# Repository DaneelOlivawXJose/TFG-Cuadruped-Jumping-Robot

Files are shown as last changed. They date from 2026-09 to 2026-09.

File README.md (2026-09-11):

<div align="center">

# Jumping Quadruped Robot
### Mechatronic Prototype for Height- and Direction-Controlled Jumping

*A quadruped robot built from scratch with an integrated spring-loaded jump mechanism, capable of executing software-controlled jumps with programmable height and direction.*








</div>

---

## 📽️ Demo

<p align="center">
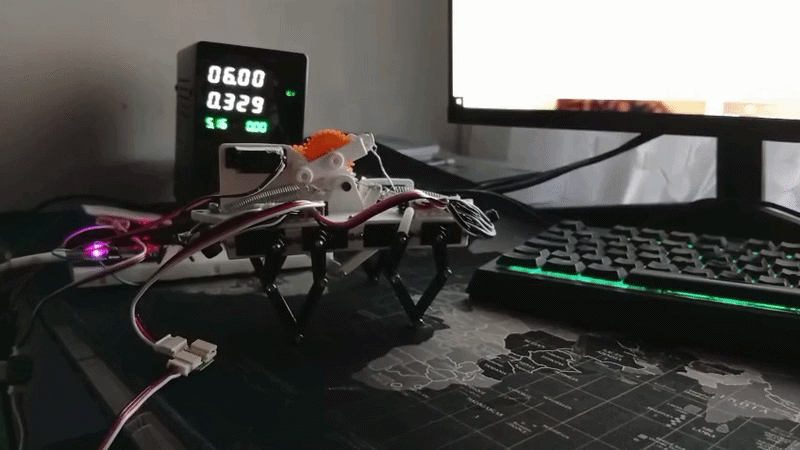
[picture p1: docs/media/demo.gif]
Robot jump demo
  
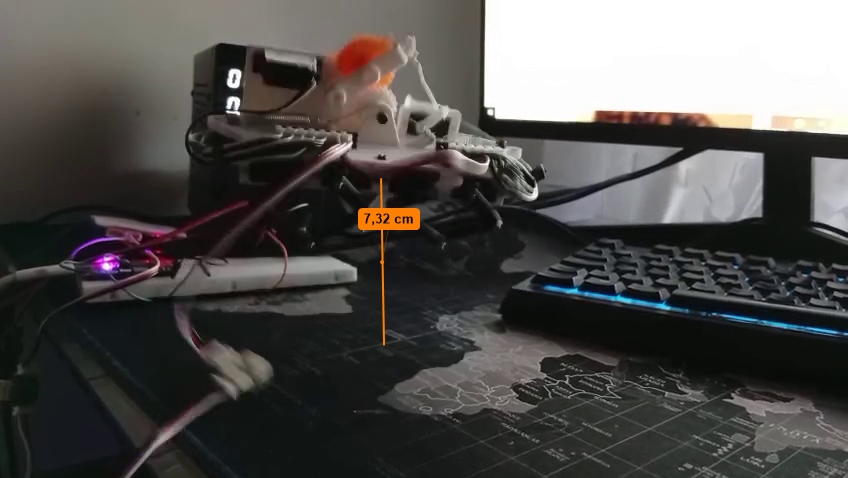
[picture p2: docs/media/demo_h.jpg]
Robot jump height
  
</p>

---

## 🧭 Overview

This repository contains the full mechatronic development of my **Final Degree Thesis (TFG)**: a **quadruped robot designed and built entirely from scratch**, mechanically capable of storing elastic energy in a spring system and releasing it on command to perform a **jump whose height and direction are controlled entirely in software**.

The project was developed end-to-end, across every layer a real robotic product needs:

- **Physical modeling** — the robot's geometry, leg kinematics and jump dynamics were derived analytically, so the software controls a system whose behavior is *understood*, not just tuned by trial and error.
- **Mechanical design** (CAD, linkage synthesis, spring sizing) — SolidWorks.
- **Embedded firmware** (deterministic servo actuation bridge) — ESP32 + micro-ROS + Arduino.
- **Robot software / control** (inverse kinematics, gait generation, jump physics solver, finite-state machine) — ROS 2, C++.

The central idea: give the robot a **single high-level command** — "walk this fast," "turn this much," "jump to this height" — and let the software work out *everything* underneath: joint angles, timing, posture, spring compression, and actuation duration. No per-jump manual calibration.

---

## ✨ Key Features

- 🦵 **Custom 5-bar rhombus leg mechanism** — each leg is a symmetric 5-link linkage, actuated by only 2 servos, giving a lightweight and mechanically robust walking leg with full 2D foot-position control.
- 🧠 **Real-time inverse kinematics** — closed-form, geometry-based IK solver per leg, running at 50 Hz, converting desired foot (x, y) coordinates into servo angles with safety-clamped travel limits.
- 🚶 **Parametric gait engine** — trot-like gait generated from a single global phase clock, with independent per-leg phase offset, adjustable stride length, and live turning compensation (differential stride between left/right or front/rear legs).
- 🚀 **Physics-based jump planner** — for a given target height, the controller sweeps launch angles to find the one that **minimizes the required take-off velocity** (accounting for ground friction and take-off geometry), then derives:
  - the optimal chassis pitch angle,
  - the required spring compression (2 springs in series + 2 in parallel),
  - the exact servo actuation time needed to load that compression through the gearbox/reel transmission.
- 🎯 **Direction control** — jump distance/direction is decoupled from height via the same solver, keeping the mechanism within the physically viable spring-compression range.
- ⚙️ **Spring-loaded release mechanism** — a compact latch (ratchet + trigger servo) loads the spring pack via a geared winch and releases it on a single software command.
- 🔗 **PC ↔ MCU split architecture** — all heavy computation (IK, gait, jump dynamics) runs centralized on a PC via ROS 2; a lightweight ESP32 running micro-ROS acts purely as a real-time servo driver, keeping the embedded side simple and deterministic.
- 🧩 **Finite-state machine control** — clean state machine (`REPOSO`, `ANDAR`, `AGACHADO`, `PREPARAR_SALTO`, `CARGAR_MUELLE`, `LIBERAR_MUELLE`, `RECUPERAR_REPOSO`) governing the full walk → crouch → arm → jump → recover sequence, with built-in safety pauses between behaviors.

---

## 🏗️ How the Architecture Works (Intuitive Overview)

Think of the system as a **brain-and-spine** split:

- **The brain (PC, ROS 2 node `nodo_robot`)** thinks in the world of physics: leg positions in meters, chassis angles in degrees, target jump heights. It never talks about "servo 3" or "PWM 715" — it reasons about *where the foot should be* and *what height the robot should reach*.
- **The spine (ESP32, `nodo_esp32_esclavo`)** doesn't think at all — it just receives a list of 10 numbers 50 times a second and writes them straight to the servos as fast as the serial bus allows. It has zero knowledge of gait, jumping, or geometry.

This split exists on purpose: **all the "smart" logic lives in one place, in a language and environment (ROS 2 / C++ on a PC) that's easy to debug, log, and iterate on**, while the embedded side stays minimal and rock-solid.

```mermaid
flowchart LR
    subgraph PC["🖥️ PC — ROS 2 node: nodo_robot (50 Hz loop)"]
        C[Finite State Machine] --> A[Gait Generator]
        C --> B[Jump Physics Solver]
        A --> D[Inverse Kinematics]
        B --> D
        D --> E["/servo_poses\n(Int32MultiArray, 10 values)"]
        B --> F["/cmd_meta_salto\n(spring-load time, ms)"]
    end

    G["Commands\n/cmd_vel · /cmd_estado · /cmd_salto"] --> C

    subgraph MCU["🔧 ESP32 — nodo_esp32_esclavo (micro-ROS + Arduino)"]
        E --> H[SCServo Driver]
        F --> H
        H --> I["10 Smart Servos\n(8 leg joints + ratchet + trigger)"]
    end

    I -.->|"physical spring loaded"| J["/estado_salto_listo"] --> C
```

**Message flow, step by step:**

1. The PC node computes, every 20 ms, the 10 target servo positions (2 per leg × 4 legs + ratchet + trigger) and publishes them as a single `Int32MultiArray` on `/servo_poses`.
2. The ESP32 subscribes to that same topic. On every message, it loops over its local `ids[]` array and calls `sc.WritePos(id, position, 0, 0)` for each of the 9 physical servos — "0, 0" meaning *move now, at full effort*, with no queued interpolation, since all the interpolation already happened on the PC side.
3. For the jump, a second, independent channel (`/cmd_meta_salto`) tells the ESP32/loading electronics *how long* to run the winch to compress the spring by the exact amount the physics solver calculated — decoupled from the 50 Hz pose stream because it's a one-shot timed action, not a continuous pose.
4. A feedback topic (`/estado_salto_listo`) lets the loading stage tell the PC "the spring is armed," which is what actually triggers the transition into the jump preparation state — the PC never assumes timing, it waits for confirmation.

---

## 🦿 Mechanical Design (SolidWorks)

| Subsystem | Description |
|---|---|
| **Leg linkage** | 5-bar (rhombus) mechanism per leg — two proximal links driven by servos, meeting at a shared distal tip, producing a controllable 2D foot trajectory with only 2 actuators per leg (8 total for 4 legs). |
| **Jump mechanism (2D)** | A single 2-servo, gear-reduced winch mechanism: one servo **loads** the spring pack (via a geared reel/cable transmission), the second servo (**trigger**) instantly **releases** a ratchet, converting stored elastic energy into a controlled jump impulse. |
| **Spring pack** | 4 extension/compression springs arranged as **2 in series + 2 in parallel**, sized to store the energy required for the target jump range while keeping the required compression within the mechanism's physical travel limit. |
| **Chassis** | Designed to tilt (pitch) on command — the take-off angle needed for an efficient jump is achieved by actively inclining the chassis rather than adding an extra actuator. |

<p align="center">
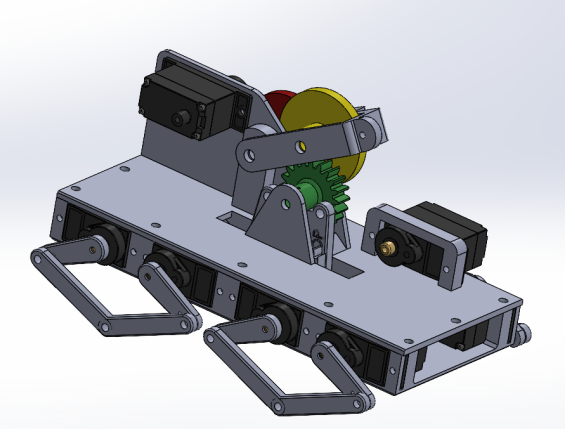
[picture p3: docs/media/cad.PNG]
CAD render
  
</p>

---

## 🧠 Inverse Kinematics — How a Leg "Knows" Where to Put Its Foot

Each leg is modeled as a **triangle-based geometric problem**, not a numerical/iterative solver — this keeps it fast enough to run for all 4 legs, every 20 ms, on a modest CPU.

Given a desired foot position `(x, y)` relative to the leg's hip:

1. The two servo pivots are separated by a fixed distance `D_PATA`, so each pivot "sees" the foot at a different angle and distance — this gives two auxiliary triangles (`α₁, a₁` and `α₂, a₂`).
2. For each triangle, the **law of cosines** is applied between the known link lengths (`L1, L2` proximal / `L3, L4` distal) and the computed distance to the foot, to isolate the internal joint angle.
3. If the required foot position is geometrically unreachable (the law-of-cosines argument falls outside `[-1, 1]`), the solver simply skips the update — a built-in safety check against invalid commands.
4. The two resulting angles (`θ1`, `θ2`) are converted from **degrees to raw servo PWM counts** using a **per-servo linear calibration** (`gradosAPasos`) — every leg has its own measured "horizontal" and "fully-down" PWM reference points, because no two servos or mechanical assemblies are perfectly identical after manual assembly.
5. Every output is **clamped** to a calibrated safe PWM range per servo, so a bad computation can never physically over-drive a joint into the mechanism.

This same IK function is reused everywhere in the code — walking, crouching, tilting for the jump, and holding the recovery posture — the *only* thing that changes between behaviors is what `(x, y, θ_chassis)` gets fed into it.

---

## 🚶 Gait Generation — How the Robot Walks

The walking gait is built from a **single global clock** shared by all 4 legs:

- A continuous timer produces a phase value `t_global ∈ [0, 1)` that repeats every `CICLO_MS` milliseconds — this is the "heartbeat" of the gait.
- Each leg is assigned a **fixed phase offset** (`desfase`): 0.75, 0.50, 0.25, 0.00 — spacing the 4 legs evenly around the gait cycle to produce a stable trot-like pattern where diagonal legs move together.
- Within its own local phase, each leg's foot follows a **two-phase trajectory**:
  - **Flight phase** (`t_local < FRACCION_AIRE`): the foot lifts off the ground and swings forward along a **sinusoidal arc**, from `-stride/2` to `+stride/2` in x, with a smooth lift-and-land height profile in y.
  - **Stance phase** (remaining time): the foot stays on the ground (`y = ALTURA_SUELO`) and slides backward in a straight line from `+stride/2` to `-stride/2`, which is what actually pushes the robot forward.
- **Turning** is achieved without any extra actuator: front legs and rear legs receive **opposite stride-length corrections** (`± compensacion_giro`), so one side of the robot takes shorter steps than the other — exactly like a tank-steering effect, driven purely by `angular.z` from the velocity command.
- **Speed control** is a direct, linear mapping from the commanded `linear.x` / `angular.z` (standard ROS 2 `Twist` message on `/cmd_vel`) to stride length and turn compensation — so the robot can be driven with any standard ROS 2 teleoperation tool.

---

## 🎮 Control — The Finite-State Machine

All robot behavior is governed by a single state machine, updated once per 20 ms control cycle:

```mermaid
stateDiagram-v2
    [*] --> REPOSO
    REPOSO --> ANDAR: /cmd_vel ≠ 0
    ANDAR --> REPOSO: /cmd_vel = 0
    REPOSO --> AGACHADO: /cmd_estado = 1
    REPOSO --> CARGAR_MUELLE: /cmd_salto or /cmd_estado = 2
    CARGAR_MUELLE --> PREPARAR_SALTO: spring loaded\n(/estado_salto_listo = 1)
    PREPARAR_SALTO --> LIBERAR_MUELLE: target posture reached
    LIBERAR_MUELLE --> RECUPERAR_REPOSO: trigger held 0.5 s
    RECUPERAR_REPOSO --> REPOSO: posture recovered (3 s ramp)
```

Two design details worth highlighting:

- **Every state transition passes through a brief `REPOSO` safety pause** (`CICLOS_PAUSA_ESTADO`) before continuing — this prevents abrupt jumps in servo commands whenever the operator switches behaviors, protecting both the mechanism and the servos.
- **Smooth interpolated transitions** (`iniciarTransicion` / `actualizarTransicion`) are used for anything involving posture change over time — crouching down, tilting for the jump, and recovering afterward — using simple **linear interpolation over a fixed duration**, driven by the ROS 2 clock rather than a fixed number of loop iterations, so timing stays consistent regardless of any missed control cycles.

---

## 🧮 The Jump Physics Engine

The core intellectual contribution of the project is `calcularParametrosSalto()`: given only a **target jump height**, the controller solves a small optimization problem in real time, entirely from first-principles physics — no lookup tables, no empirical curve fitting for the trajectory itself.

**Step by step:**

1. **Sweep launch angles** `θ ∈ [atan(1/μ), 90°)`, where the lower bound comes from the **friction cone** — below that angle, the push-off leg would slip on the ground instead of launching the robot.
2. For each candidate angle, compute the **take-off height** contributed by the extended jumping leg's geometry (`z₀ = L·sin θ`), and combine it with the target distance and height to solve the **projectile-motion equation** for the minimum take-off velocity `v₀` that satisfies both constraints simultaneously.
3. **Select the angle that minimizes `v₀²`** — i.e., the most energy-efficient launch geometry for reaching that specific height and distance.
4. Convert the optimal launch angle into the **chassis pitch angle** the robot must adopt before firing, and the **posture height** the legs must be commanded to.
5. **Back-solve the spring compression `Δx`** needed to deliver `v₀`, from the effective combined stiffness of the spring pack (`K1 + K2`, arranged in series/parallel) and an empirically measured **mechanical efficiency factor**, using energy balance under gravity.
6. Convert `Δx` into a **servo actuation time** by unrolling the full mechanical transmission — gear ratios (`Z1…Z5`), winch/reel radius, and maximum servo angular speed — so the loading servo runs for *exactly* as long as needed and no more.
7. **Built-in feasibility check:** if the required spring compression exceeds the mechanism's physical travel limit, the jump is automatically flagged as *not viable* and safely aborted before any hardware command is sent — the operator never has to manually validate a requested height.

This turns "jump to height *h*" into a **single ROS 2 topic publish** (`/cmd_salto`, a `Float64` in meters) — the robot works out the rest, prints a full diagnostic (`v₀`, launch angle, spring compression, posture height) to the log, and either executes or safely refuses the jump.

---

## 🔌 Embedded Firmware (ESP32)

The ESP32 side is intentionally "dumb by design":

- Runs **micro-ROS over serial**, appearing to the PC as a regular ROS 2 node (`nodo_esp32_esclavo`) with a single subscription to `/servo_poses`.
- On every incoming `Int32MultiArray`, it iterates over its local ID map and issues a `WritePos(id, position, time=0, speed=0)` command to each of the 9 **Feetech SCS smart serial servos** over a dedicated UART running at 1 Mbps.
- `time = 0, speed = 0` deliberately disables the servo's own internal interpolation — every trajectory point is already the *final* result of the PC-side interpolation, so the servo is told to snap to it immediately, keeping timing entirely under the 50 Hz ROS 2 loop's control.
- An onboard LED blinks on every received message (useful as a zero-cost "is the link alive" diagnostic) and blinks differently on a micro-ROS initialization failure — a small but genuinely useful debugging aid when the robot is untethered.

---

## 🛠️ Tech Stack

| Layer | Technology |
|---|---|
| Mechanical design | SolidWorks (linkage synthesis, spring sizing, motion study) |
| High-level control | ROS 2 (C++), custom node with 50 Hz control loop |
| Kinematics & dynamics | Closed-form inverse kinematics, projectile-motion jump solver |
| Embedded firmware | ESP32, Arduino framework, micro-ROS |
| Actuation | Feetech SCS smart serial servos (`SCServo` library) |
| Communication | micro-ROS over serial (PC ↔ ESP32), ROS 2 topics for teleop |

---

## 📁 Repository Structure

```
├── cad/                    # SolidWorks parts, assemblies, drawings
├── firmware/
│   └── esp32_servo_bridge/ # Arduino + micro-ROS servo driver
├── ros2_ws/
│   └── src/tfg_salto/      # ROS 2 C++ package: gait, IK, jump planner, FSM
├── docs/
│   └── media/              # Renders, photos, GIFs, diagrams
└── README.md
```

---

## 🚀 Getting Started

### 1. Flash the ESP32
Upload `firmware/esp32_servo_bridge` via Arduino IDE / PlatformIO (requires the `micro_ros_arduino` and `SCServo` libraries).

### 2. Bring up the micro-ROS bridge on the PC
```bash
ros2 run micro_ros_agent micro_ros_agent serial --dev /dev/ttyUSB0
```

### 3. Build and launch the robot controller
```bash
colcon build --packages-select tfg_salto
source install/setup.bash
ros2 run tfg_salto tfg_robot
```

### 4. Drive it
```bash
python3 teleop_teclado.py
```

### 5. Command specific behaviors
| Topic | Type | Effect |
|---|---|---|
| `/cmd_vel` | `geometry_msgs/Twist` | Walk / turn (linear.x → stride length, angular.z → turn compensation) |
| `/cmd_estado` | `std_msgs/Int32` | `0` walk · `1` crouch · `2` load spring · `3` idle |
| `/cmd_salto` | `std_msgs/Float64` | Trigger a full jump sequence to a target height (m) |
| `/estado_salto_listo` | `std_msgs/Int32` | (internal) confirms the spring is physically armed |

**Example — jump to 4 cm:**
```bash
ros2 topic pub -1 /cmd_salto std_msgs/msg/Float64 "{data: 0.04}"
```

The controller will log the full computed jump plan before executing it, e.g. take-off velocity, optimal launch/pitch angle, required spring compression, and target posture height — making every jump fully traceable and reproducible.

---

## 📊 Mechanism Results

| Metric | Value |
|---|---|
| Target jump height range tested | **2-6cm** (e.g. 2–6 cm) |
| Maximum controlled jump height achieved | **6cm** |
| Mechanism efficiency | **75%** |
| Jump height accuracy (measured vs. commanded) | **99,6%** |
| Jump distance / direction range | **TBD** |
| Spring-loading time (typical) | **7s** (derived from `movimiento_servo_`, ms) |
| Full jump sequence duration (load → launch → recover) | **15s** |
| Total robot mass | **370g** |

---

## 🔭 Future Work

- Closed-loop landing detection and impact absorption
- IMU-based feedback for in-flight orientation correction
- Onboard (non-centralized) computation for full autonomy
- 3D jump control (adding lateral steering to the current 2D jump plane)

---

## 👤 Author

**Jose Segura Montes** — Bachelor's Thesis (TFG), Degree in Electronics, Robotics and Mechatronics, Universidad de Málaga, [2026]
📧 jose.segura.montes@gmail.com · 🔗 [LinkedIn](www.linkedin.com/in/jose-segura-montes) · 🔗 [Portfolio](https://portfolio-github-8fqt.vercel.app)

---

## 📄 License

This project is licensed under the MIT License — see [`LICENSE`](LICENSE) for details.

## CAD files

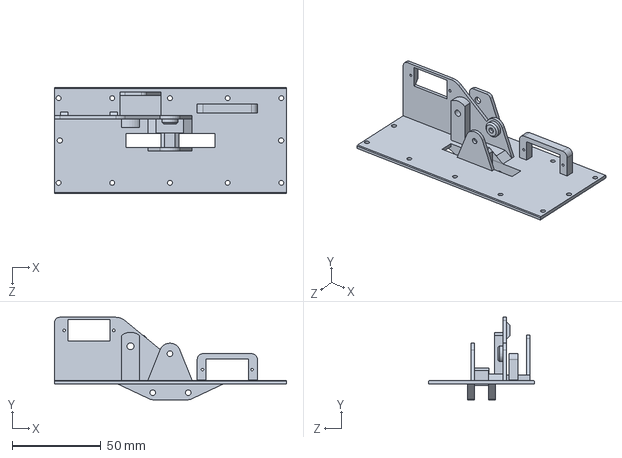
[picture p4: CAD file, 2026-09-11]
cad/2026 Jumper Robot/vehicle/chasis superior completo.SLDPRT
131.0 x 46.6 x 60.0 mm

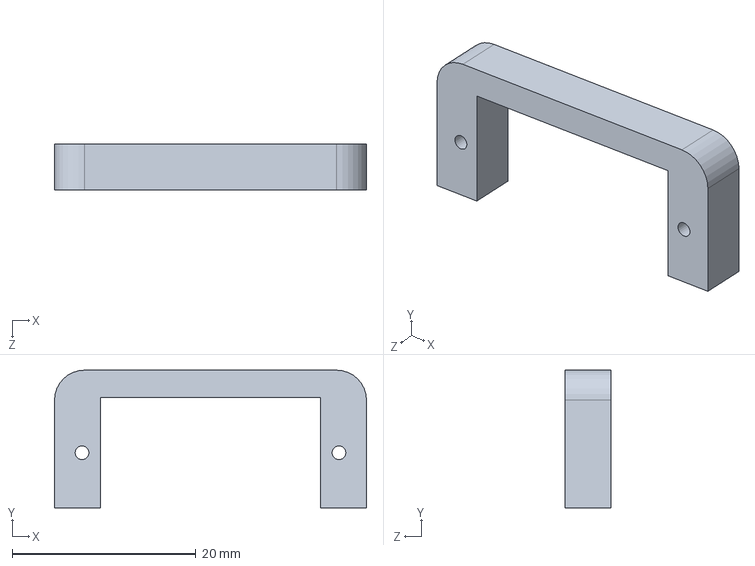
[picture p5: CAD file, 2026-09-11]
cad/2026 Jumper Robot/vehicle/soporteservo.SLDPRT
34.0 x 15.0 x 5.00 mm

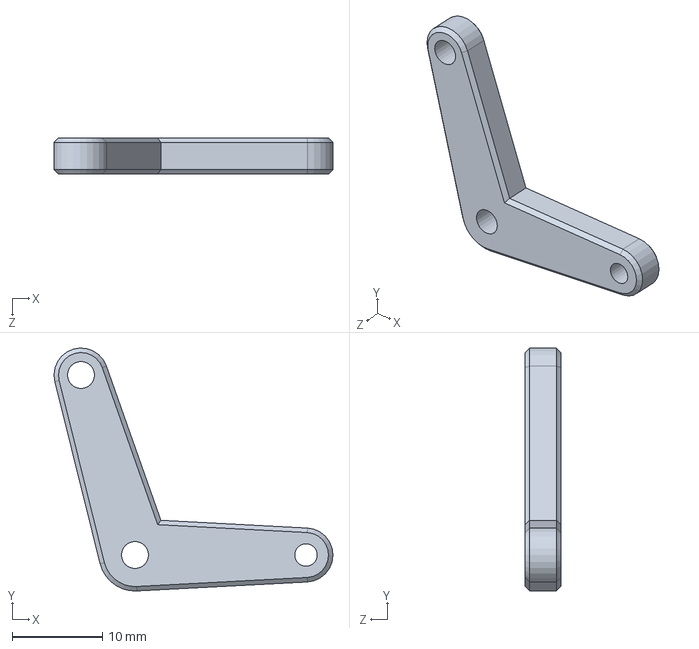
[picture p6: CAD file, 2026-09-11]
cad/2026 Jumper Robot/vehicle/link1-central-2.SLDPRT
31.0 x 27.0 x 4.00 mm

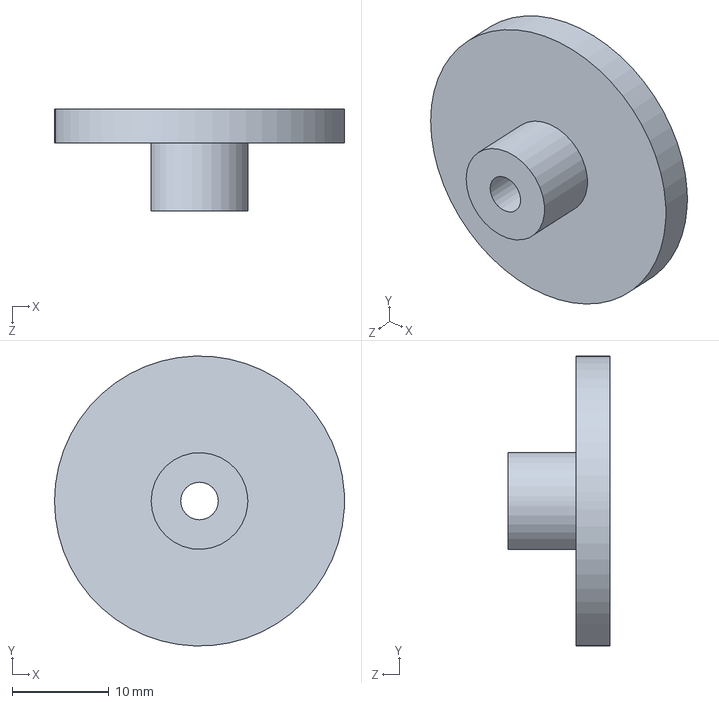
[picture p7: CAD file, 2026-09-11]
cad/2026 Jumper Robot/vehicle/engranaje30x10.SLDPRT
30.0 x 30.0 x 10.5 mm

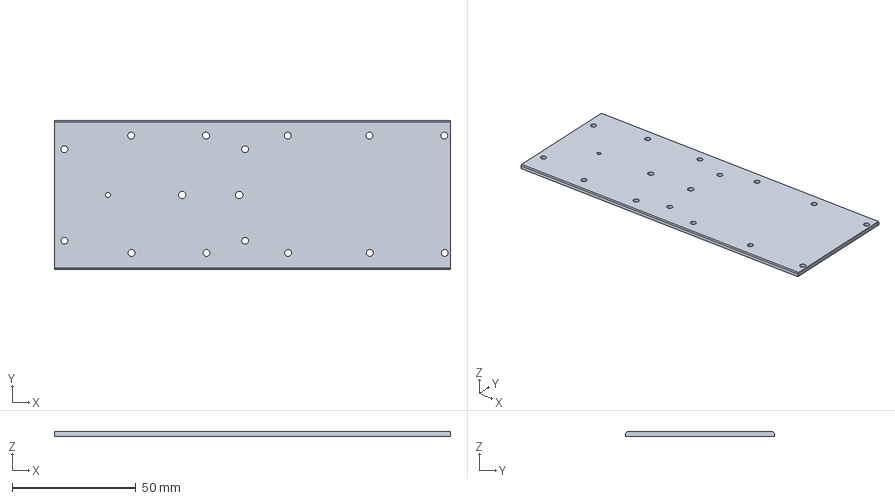
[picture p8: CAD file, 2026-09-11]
cad/2026 Jumper Robot/vehicle/Tapa-chasis.3mf
160.0 x 60.0 x 2.00 mm

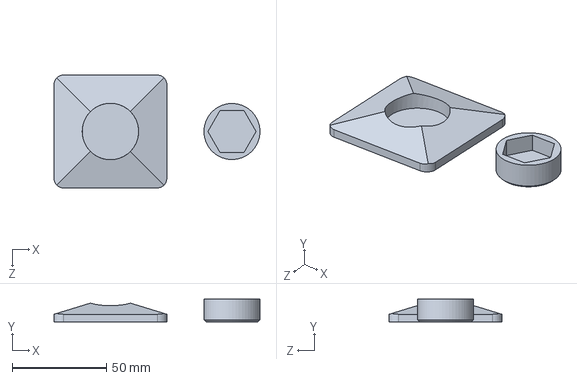
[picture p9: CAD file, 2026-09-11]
cad/2026 Jumper Robot/vehicle/base patas estructura cámaras.SLDPRT
109.5 x 12.0 x 60.0 mm

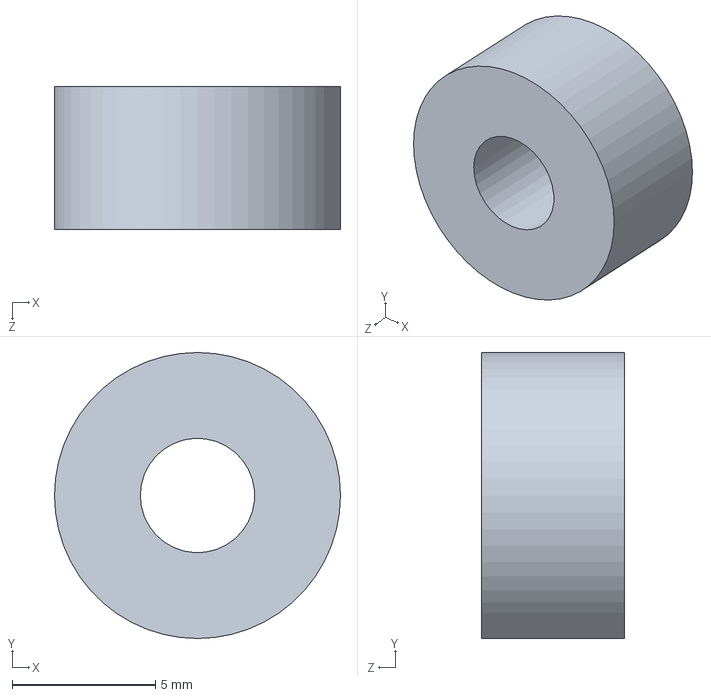
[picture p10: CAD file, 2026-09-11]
cad/2026 Jumper Robot/vehicle/engranaje-10.SLDPRT
10.0 x 10.0 x 5.00 mm

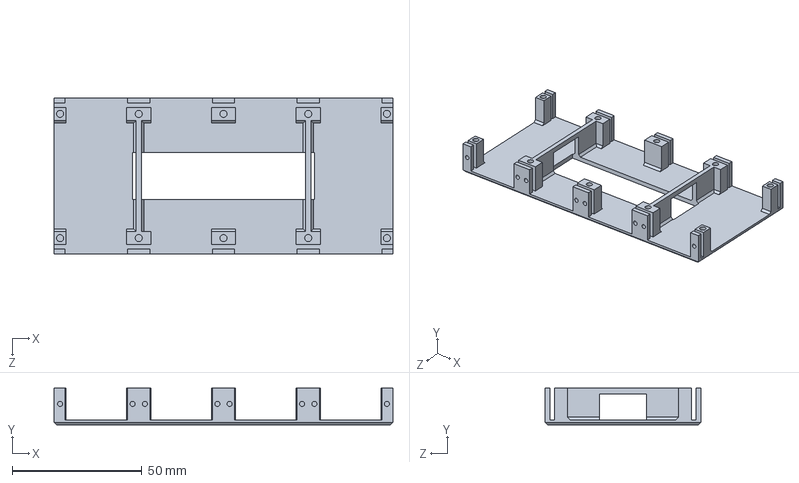
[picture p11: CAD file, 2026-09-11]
cad/2026 Jumper Robot/vehicle/chasis.SLDPRT
130.4 x 14.2 x 60.0 mm

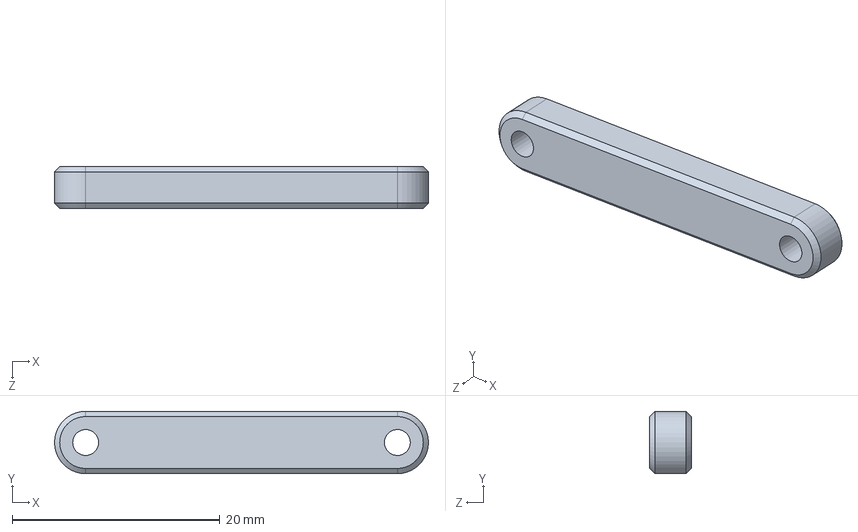
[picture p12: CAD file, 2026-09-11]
cad/2026 Jumper Robot/vehicle/link2-central.SLDPRT
36.0 x 6.00 x 4.00 mm

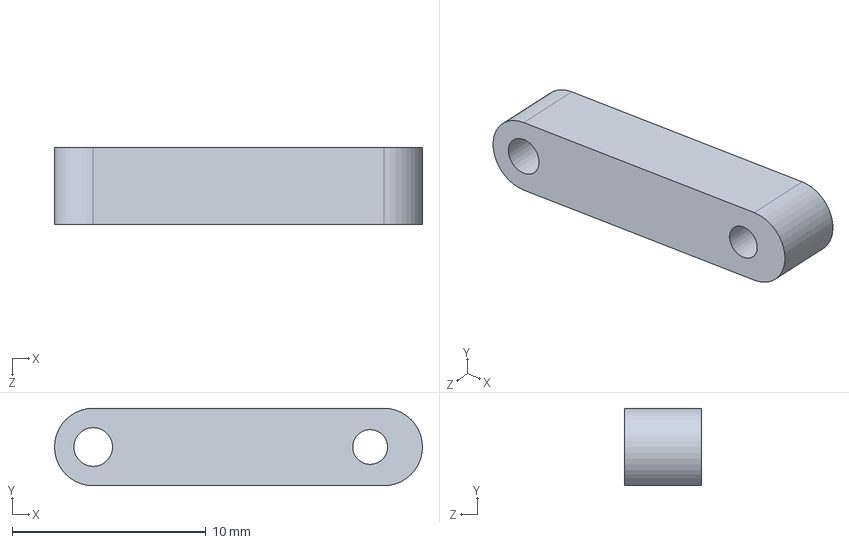
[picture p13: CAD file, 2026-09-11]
cad/2026 Jumper Robot/vehicle/horn_aprox.SLDPRT
19.0 x 4.00 x 4.00 mm

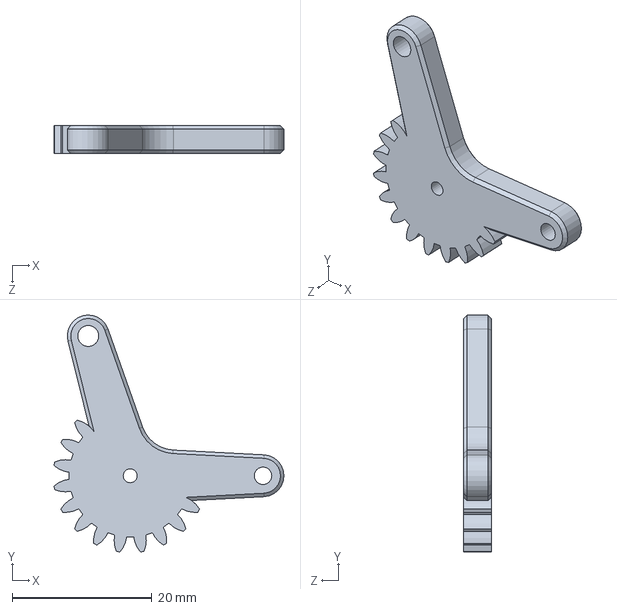
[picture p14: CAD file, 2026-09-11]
cad/2026 Jumper Robot/vehicle/link1-central.SLDPRT
32.9 x 33.9 x 4.00 mm

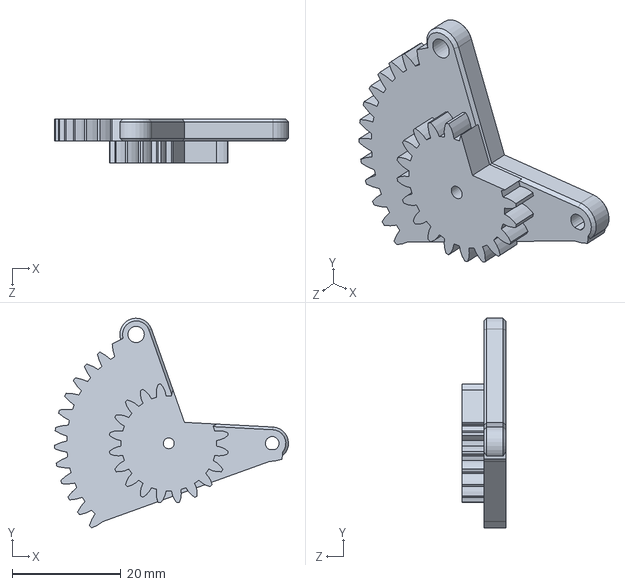
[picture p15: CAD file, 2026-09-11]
cad/2026 Jumper Robot/vehicle/link1-LEFT-central.SLDPRT
43.0 x 38.5 x 8.00 mm

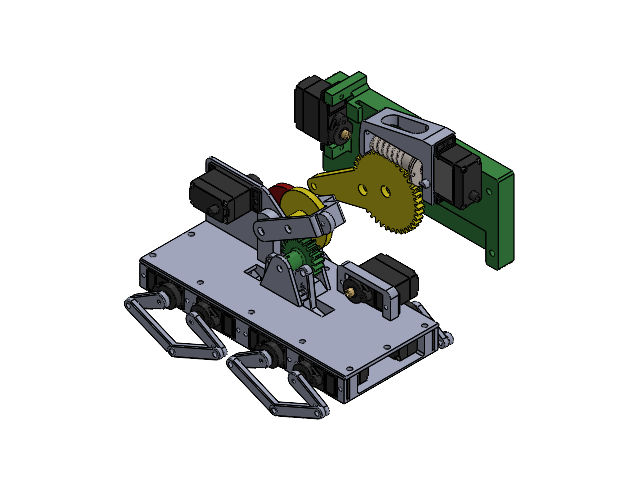
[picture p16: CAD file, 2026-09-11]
cad/2026 Jumper Robot/vehicle/Ensamblaje global.SLDASM
base2
main-gear3
91772A071_NO THREADS_Passivated 18-8 Stainless Steel Pan Head Phillips Screw_1.step x 48
eBom-FreeParts_1.step x 12
bloque_worm2
polea 10_modulo 1 simple
chasis
link1 x 8
link2 x 8
Tapa-chasis
link1-central-2
link2-central x 2
link1-LEFT-central-2
soporte carrete y engranajes
ejepolea
engranaje30x10 x 2
bloqueo resorte
soporteservo

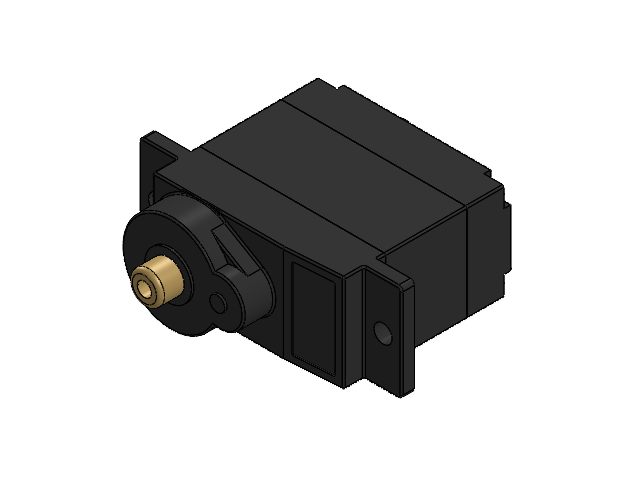
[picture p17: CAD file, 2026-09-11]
cad/2026 Jumper Robot/vehicle/Feetech SCS0009 v9.SLDASM
91772A071_NO THREADS_Passivated 18-8 Stainless Steel Pan Head Phillips Screw_1.step x 4
eBom-FreeParts_1.step

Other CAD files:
cad/2026 Jumper Robot/vehicle/Ensamblaje Vahículo Saltador 2_2024.SLDASM
cad/2026 Jumper Robot/vehicle/Ensamblaje Pata.SLDASM
cad/2026 Jumper Robot/vehicle/Ensamblaje chasis superior.SLDASM
cad/2026 Jumper Robot/vehicle/Ensamblaje chasis superiopr.SLDASM
cad/2026 Jumper Robot/vehicle/Ensamblaje chasis superior.STL
cad/2026 Jumper Robot/vehicle/Tapa-chasis.STL
cad/2026 Jumper Robot/vehicle/base patas estructura cámaras.3mf
cad/2026 Jumper Robot/vehicle/base patas estructura cámaras.STL
cad/2026 Jumper Robot/vehicle/bloqueo resorte.3mf
cad/2026 Jumper Robot/vehicle/bloqueo resorte.SLDPRT
cad/2026 Jumper Robot/vehicle/bloqueo resorte.STL
cad/2026 Jumper Robot/vehicle/chasis superior completo.3mf
cad/2026 Jumper Robot/vehicle/chasis superior completo.STL
cad/2026 Jumper Robot/vehicle/chasis.3mf
cad/2026 Jumper Robot/vehicle/chasis.STL
cad/2026 Jumper Robot/vehicle/ejepolea.3mf
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

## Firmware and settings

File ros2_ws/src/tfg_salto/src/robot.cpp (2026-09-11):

#include "tfg_salto/robot.hpp"


Robot::Robot() : Node("nodo_robot")
{
    // --- Inicializar patas: {canal_s1, canal_s2, pwm_h_s1, pwm_d_s1, pwm_h_s2, pwm_d_s2}, desfase, inversor_x ---
    misPatas_[0] = { {1, 8, 299, 584, 941, 671}, 0.75f,  1.0f };
    misPatas_[1] = { {3, 2, 715, 992, 890, 634}, 0.50f,  1.0f };
    misPatas_[2] = { {7, 6, 183, 466, 907, 630}, 0.25f, -1.0f };
    misPatas_[3] = { {4, 5, 650, 310, 475, 754}, 0.00f,  1.0f };

    tiempo_inicio_ = this->now();

    // --- Publishers ---
    pub_poses_      = this->create_publisher<std_msgs::msg::Int32MultiArray>("servo_poses",    10);
    pub_meta_salto_ = this->create_publisher<std_msgs::msg::Int32>          ("cmd_meta_salto", 10);

    // --- Subscriptores ---
    sub_vel_ = this->create_subscription<geometry_msgs::msg::Twist>(
        "cmd_vel", 10, std::bind(&Robot::cmd_vel_callback, this, std::placeholders::_1));

    sub_estado_ = this->create_subscription<std_msgs::msg::Int32>(
        "cmd_estado", 10, std::bind(&Robot::cmd_estado_callback, this, std::placeholders::_1));

    sub_salto_ = this->create_subscription<std_msgs::msg::Float64>(
        "cmd_salto", 10, std::bind(&Robot::cmd_salto_callback, this, std::placeholders::_1));

    sub_salto_listo_ = this->create_subscription<std_msgs::msg::Int32>(
        "estado_salto_listo", 10, std::bind(&Robot::salto_listo_callback, this, std::placeholders::_1));

    // --- Timer principal: 50 Hz (20 ms) ---
    timer_control_ = this->create_wall_timer(
        20ms, std::bind(&Robot::bucle_control_callback, this));

    RCLCPP_INFO(this->get_logger(), "Nodo Robot iniciado.");
}

Robot::~Robot()
{
    RCLCPP_INFO(this->get_logger(), "Apagando nodo del robot.");
}

// ============================================================
// BUCLE PRINCIPAL (50 Hz)
// ============================================================

void Robot::bucle_control_callback()
{
    // Al cambiar de estado, se hace una pausa de 1 s en REPOSO antes de continuar
    if (cambiado_) {
        estado_previo_ = estado_actual_;
        estado_actual_ = REPOSO;
        ciclos_espera_ = CICLOS_PAUSA_ESTADO;
        cambiado_ = false;
    }

    switch (estado_actual_) {
        case ANDAR:           estado_andar();           break;
        case AGACHADO:        estado_agachado();        break;
        case REPOSO:          estado_reposo();          break;
        case PREPARAR_SALTO:  estado_preparar_salto();  break;
        case CARGAR_MUELLE:   estado_cargar_muelle();   break;
        case LIBERAR_MUELLE:  estado_liberar_muelle();  break;
        case RECUPERAR_REPOSO: estado_recuperar_reposo(); break;
    }
}

// ============================================================
// LÓGICA DE ESTADOS
// ============================================================

void Robot::estado_andar()
{
    // Tiempo global normalizado [0, 1) dentro del ciclo de marcha
    auto tiempo_actual = this->now() - tiempo_inicio_;
    double ms = tiempo_actual.nanoseconds() / 1e6;
    float t_global = static_cast<float>(fmod(ms, CICLO_MS)) / CICLO_MS;

    std_msgs::msg::Int32MultiArray msg;
    msg.data.resize(10);

    for (int i = 0; i < 4; i++) {
        // Cada pata tiene su desfase de fase en el ciclo
        float t_local = fmod(t_global + misPatas_[i].desfase, 1.0f);

        // Las patas delanteras (0,1) restan la compensación y las traseras (2,3) la suman
        float longitud = longitud_paso_ + ((i < 2) ? -compensacion_giro_ : compensacion_giro_);

        float x, y;
        calcularTrayectoriaPaso(t_local, longitud, x, y);

        int s1, s2;
        calcularPataIK(x * misPatas_[i].inversor_x, y, misPatas_[i], s1, s2);
        msg.data[i*2]   = s1;
        msg.data[i*2+1] = s2;
    }

    msg.data[8] = 930;                    // Ratchet en posición de marcha
    msg.data[9] = SERVO_GATILLO_CERRADO;  // Gatillo cerrado durante la marcha
    pub_poses_->publish(msg);
}

void Robot::estado_agachado()
{
    // Baja suavemente el chasis hasta y = 0.02 m (máximo agachado)
    constexpr float Y_AGACHADO = 0.02f;
    constexpr float PASO_BAJA  = 0.0005f;

    if (altura_chasis_ > Y_AGACHADO) {
        altura_chasis_ = std::max(Y_AGACHADO, altura_chasis_ - PASO_BAJA);
    }

    publicarPoses(0.0f, altura_chasis_, 0.0f, 0, SERVO_GATILLO_CERRADO);
}

void Robot::estado_reposo()
{
    constexpr float PASO_ALTURA = 0.0005f;
    constexpr float PASO_THETA  = 0.5f;    // Grados por ciclo al recuperar inclinación

    // Recuperar altura suavemente hacia Y_REPOSO
    if (std::abs(altura_chasis_ - Y_REPOSO) > PASO_ALTURA) {
        altura_chasis_ += (Y_REPOSO > altura_chasis_) ? PASO_ALTURA : -PASO_ALTURA;
    } else {
        altura_chasis_ = Y_REPOSO;
    }

    // Recuperar inclinación suavemente hacia 0°
    theta_actual_ = std::max(0.0f, theta_actual_ - PASO_THETA);

    // Si el estado previo era PREPARAR_SALTO, el muelle sigue cargado: no soltar el gatillo
    int gatillo = (estado_previo_ == PREPARAR_SALTO) ? SERVO_GATILLO_ABIERTO : SERVO_GATILLO_CERRADO;

    publicarPoses(0.0f, altura_chasis_, theta_actual_ * (M_PI / 180.0f), 0, gatillo);

    // Volver al estado anterior tras la pausa
    if (ciclos_espera_ > 0) {
        ciclos_espera_--;
    } else {
        estado_actual_ = estado_previo_;
    }
}

void Robot::estado_cargar_muelle()
{
    // Mantener las patas rígidas en reposo con el gatillo armado
    publicarPoses(0.0f, altura_chasis_, 0.0f, 0, SERVO_GATILLO_ABIERTO);

    // Enviar la orden de tensado al ESP32 una sola vez
    if (!orden_salto_enviada_)
    {
        std_msgs::msg::Int32 msg;
        msg.data = movimiento_servo_;
        pub_meta_salto_->publish(msg);
        RCLCPP_INFO(this->get_logger(), "Orden de tensado al ESP32: %d ms", movimiento_servo_);
        orden_salto_enviada_ = true;
    }
}

void Robot::estado_preparar_salto()
{
    // Fase 1: Inclina el chasis y adapta la altura a la longitud física de la pata contraída
    if (!transicion_activa_ && !timer_liberacion_set_)
    {
        RCLCPP_INFO(this->get_logger(), "Ajustando postura a %.1f° y %.3f m de altura...", theta_opt_deg_, y_prep_salto_);
        
        // Aplicamos la altura dinámica (y_prep_salto_) en lugar del Z0 estático
        iniciarTransicion(static_cast<float>(y_prep_salto_), static_cast<float>(theta_opt_deg_), 2.5);
        timer_liberacion_set_ = true; 
    }

    if (actualizarTransicion(altura_chasis_, theta_actual_))
    {
        estado_actual_ = LIBERAR_MUELLE;
        fase_liberacion_ = 0;
        timer_disparo_set_ = false;
    }

    publicarPoses(0.0f, altura_chasis_, theta_actual_ * (M_PI / 180.0f), 0, SERVO_GATILLO_ABIERTO);
}

void Robot::estado_liberar_muelle()
{
    // Fase 2: Liberar el mecanismo (ID 10 a 800)
    if (fase_liberacion_ == 0) {
        RCLCPP_INFO(this->get_logger(), "¡SALTO! Liberando mecanismo ID 10 a 800...");
        
        // gatillo_s10 (índice 9 en tu array) lo enviamos a 800
        publicarPoses(0.0f, altura_chasis_, theta_actual_ * (M_PI / 180.0f), 0, 800);
        
        tiempo_fase_ = this->now();
        fase_liberacion_ = 1;
    } 
    else {
        // Mantén la publicación del gatillo suelto para asegurarnos de que el servo llega
        publicarPoses(0.0f, altura_chasis_, theta_actual_ * (M_PI / 180.0f), 0, 800);
        
        // Esperamos medio segundo mecánico para que el gatillo realmente se suelte
        if ((this->now() - tiempo_fase_).seconds() >= 0.5) {
            RCLCPP_INFO(this->get_logger(), "Recuperando posición inicial...");
            estado_actual_ = RECUPERAR_REPOSO;
            transicion_activa_ = false; // Reseteamos la bandera para el siguiente estado
        }
    }
}

void Robot::estado_recuperar_reposo()
{
    // Fase 3: Vuelve poco a poco a la posición de reposo durante 3 segundos
    if (!transicion_activa_) {
        iniciarTransicion(Y_REPOSO, 0.0f, 3.0);
    }

    // La función bloquea lógicamente el estado durante 3s
    if (actualizarTransicion(altura_chasis_, theta_actual_)) {
        RCLCPP_INFO(this->get_logger(), "Posición de reposo alcanzada. Secuencia terminada.");
        estado_actual_ = REPOSO;
        cambiado_ = true; // Activa la pausa post-estado por seguridad si la deseas
    }

    // Publicamos las poses interpoladas
    publicarPoses(0.0f, altura_chasis_, theta_actual_ * (M_PI / 180.0f), 0, SERVO_GATILLO_CERRADO);
}

// ============================================================
// CALLBACKS ROS
// ============================================================

void Robot::cmd_vel_callback(const geometry_msgs::msg::Twist::SharedPtr msg)
{
    bool parado = (msg->linear.x == 0.0 && msg->angular.z == 0.0);

    if (parado) {
        // Solo volver a REPOSO si no estamos en alguna fase del salto
        bool en_salto = (estado_actual_ == AGACHADO     ||
                         estado_actual_ == PREPARAR_SALTO ||
                         estado_actual_ == CARGAR_MUELLE  ||
                         estado_actual_ == LIBERAR_MUELLE);
        if (!en_salto && estado_actual_ != REPOSO) {
            estado_actual_ = REPOSO;
        }
        longitud_paso_     = 0.0f;
        compensacion_giro_ = 0.0f;
    } else {
        estado_actual_     = ANDAR;
        longitud_paso_     = static_cast<float>(msg->linear.x)  * 0.03f;
        compensacion_giro_ = static_cast<float>(msg->angular.z) * 0.002f;
    }
}

void Robot::cmd_estado_callback(const std_msgs::msg::Int32::SharedPtr msg)
{
    switch (msg->data) {
        case 0:
            RCLCPP_INFO(this->get_logger(), "→ ANDAR");
            estado_actual_ = ANDAR;
            cambiado_ = true;
            break;
        case 1:
            RCLCPP_INFO(this->get_logger(), "→ AGACHADO");
            estado_actual_ = AGACHADO;
            cambiado_ = true;
            break;
        case 2:
            RCLCPP_INFO(this->get_logger(), "→ CARGAR_MUELLE");
            iniciarSecuenciaSalto(h_objetivo_);
            break;
        case 3:
            RCLCPP_INFO(this->get_logger(), "→ REPOSO");
            estado_actual_ = REPOSO;
            cambiado_ = true;
            break;
        default:
            RCLCPP_WARN(this->get_logger(), "cmd_estado desconocido: %d", msg->data);
    }
}

void Robot::cmd_salto_callback(const std_msgs::msg::Float64::SharedPtr msg)
{
    iniciarSecuenciaSalto(msg->data);
}

void Robot::salto_listo_callback(const std_msgs::msg::Int32::SharedPtr msg)
{
    if (msg->data == 1) {
        RCLCPP_INFO(this->get_logger(), "¡Muelle cargado! Pasando a PREPARAR_SALTO.");
        estado_actual_ = PREPARAR_SALTO;
        cambiado_ = true;
    }
}

// ============================================================
// HELPER: Iniciar secuencia de salto
// ============================================================

void Robot::iniciarSecuenciaSalto(double h)
{
    h_objetivo_          = h;
    theta_actual_        = 0.0f;
    altura_chasis_       = Y_REPOSO;
    
    // Reset de todas las banderas para garantizar que un segundo salto funcione
    orden_salto_enviada_  = false;
    transicion_activa_    = false;
    timer_liberacion_set_ = false;
    timer_disparo_set_    = false;
    fase_liberacion_      = 0;
    
    estado_actual_       = CARGAR_MUELLE;
    cambiado_            = true;
    calcularParametrosSalto(h);
}

// ============================================================
// CINEMÁTICA INVERSA Y TRAYECTORIAS
// ============================================================

void Robot::calcularPataIK(float x, float y, const Pata &p, int &posS1, int &posS2) const
{
    // Ángulos auxiliares en el triángulo formado por los eslabones
    float alfa1 = atan2(y, x + D_PATA / 2.0f);
    float alfa2 = atan2(y, x - D_PATA / 2.0f);

    float a1 = std::sqrt((x + D_PATA/2.0f)*(x + D_PATA/2.0f) + y*y);
    float a2 = std::sqrt((x - D_PATA/2.0f)*(x - D_PATA/2.0f) + y*y);

    float b1 = (L1*L1 + a1*a1 - L3*L3) / (2.0f * L1 * a1);
    float b2 = (L2*L2 + a2*a2 - L4*L4) / (2.0f * L2 * a2);

    // Comprobar límite físico (argumento de acos fuera de [-1, 1])
    if (std::abs(b1) > 1.0f || std::abs(b2) > 1.0f) return;

    float theta1_deg = (alfa1 + std::acos(b1)) * (180.0f / M_PI);
    float theta2_deg = (alfa2 - std::acos(b2)) * (180.0f / M_PI);

    posS1 = gradosAPasos(p, 1, theta1_deg);
    posS2 = gradosAPasos(p, 0, theta2_deg);
}

int Robot::gradosAPasos(const Pata &p, int lado, float grados) const
{
    float pasos;
    int minSeguro, maxSeguro;

    if (lado == 0) {  // Servo 2 (inferior)
        float factor = (p.config.pwm_down_s2 - p.config.pwm_horiz_s2) / 90.0f;
        pasos    = p.config.pwm_horiz_s2 + (grados - 0.0f) * factor;
        minSeguro = std::min(p.config.pwm_horiz_s2, p.config.pwm_down_s2 - 200);
        maxSeguro = std::max(p.config.pwm_horiz_s2, p.config.pwm_down_s2 + 200);
    } else {           // Servo 1 (superior)
        float factor = (p.config.pwm_down_s1 - p.config.pwm_horiz_s1) / -90.0f;
        pasos    = p.config.pwm_horiz_s1 + (grados - 180.0f) * factor;
        minSeguro = std::min(p.config.pwm_horiz_s1, p.config.pwm_down_s1 - 200);
        maxSeguro = std::max(p.config.pwm_horiz_s1, p.config.pwm_down_s1 + 200);
    }

    return std::clamp(static_cast<int>(pasos), minSeguro, maxSeguro);
}

void Robot::calcularTrayectoriaPaso(float t_local, float longitud,
                                    float &out_x, float &out_y) const
{
    if (t_local < FRACCION_AIRE) {
        // Fase de vuelo: arco senoidal de -L/2 a +L/2
        float progreso = t_local / FRACCION_AIRE;
        out_x = -longitud / 2.0f + longitud * progreso;
        out_y = ALTURA_SUELO - ALTURA_LEVANT * std::sin(progreso * M_PI);
    } else {
        // Fase de apoyo: deslizamiento rectilíneo de +L/2 a -L/2
        float progreso = (t_local - FRACCION_AIRE) / (1.0f - FRACCION_AIRE);
        out_x = longitud / 2.0f - longitud * progreso;
        out_y = ALTURA_SUELO;
    }
}

// ============================================================
// HELPER: Publicar poses con inclinación opcional
// ============================================================

/// Calcula la IK para las 4 patas y publica el mensaje de poses.
/// @param theta_rad  Ángulo de inclinación del chasis en radianes (0 = plano).
///                   Las patas 0 y 2 (delanteras) bajan según d_pata × tan(θ).
void Robot::publicarPoses(float x_objetivo, float y_base,
                          float theta_rad,
                          int gatillo_s9, int gatillo_s10)
{
    std_msgs::msg::Int32MultiArray msg;
    msg.data.resize(10);

    for (int i = 0; i < 4; i++) {
        // Las patas delanteras (índices 0 y 2) se ajustan según la inclinación
        float y_ik = (i == 0 || i == 2)
                     ? y_base - D_PATA * std::tan(theta_rad)
                     : y_base;

        int s1, s2;
        calcularPataIK(x_objetivo * misPatas_[i].inversor_x, y_ik, misPatas_[i], s1, s2);
        msg.data[i*2]   = s1;
        msg.data[i*2+1] = s2;
    }

    msg.data[8] = gatillo_s9;
    msg.data[9] = gatillo_s10;
    pub_poses_->publish(msg);
}

// ============================================================
// GESTIÓN DE TRANSICIONES TEMPORALES
// ============================================================

void Robot::iniciarTransicion(float y_fin, float theta_fin, double duracion_segundos)
{
    y_inicial_ = altura_chasis_;
    theta_inicial_ = theta_actual_;
    y_final_ = y_fin;
    theta_final_ = theta_fin;
    duracion_transicion_ = duracion_segundos;
    tiempo_inicio_transicion_ = this->now();
    transicion_activa_ = true;
}

bool Robot::actualizarTransicion(float &out_y, float &out_theta)
{
    if (!transicion_activa_) return true;

    double transcurrido = (this->now() - tiempo_inicio_transicion_).seconds();
    
    if (transcurrido >= duracion_transicion_) {
        // Hemos terminado el tiempo asignado
        out_y = y_final_;
        out_theta = theta_final_;
        transicion_activa_ = false;
        return true;
    }

    // Calculamos el progreso entre 0.0 y 1.0
    float progreso = static_cast<float>(transcurrido / duracion_transicion_);
    
    // Interpolación lineal
    out_y = y_inicial_ + progreso * (y_final_ - y_inicial_);
    out_theta = theta_inicial_ + progreso * (theta_final_ - theta_inicial_);
    
    return false; // Aún estamos en transición
}

// ============================================================
// CÁLCULO DE PARÁMETROS DE SALTO
// ============================================================

void Robot::calcularParametrosSalto(double h_objetivo)
{
    // Rango de búsqueda del ángulo de lanzamiento
    constexpr int    RESOLUCION    = 1000;
    const double theta_min = std::atan(1.0 / MU_FRICCION);
    const double theta_max = (M_PI / 2.0) - 0.01;
    const double paso_theta = (theta_max - theta_min) / (RESOLUCION - 1);

    double v0_sq_min   = std::numeric_limits<double>::infinity();
    double theta_opt   = 0.0;

    // Búsqueda del ángulo que minimiza la velocidad de despegue necesaria.
    // Con d_min == d_max la búsqueda en d es trivial; se mantiene el doble
    // bucle por compatibilidad con futuras variaciones de la distancia.
    for (int i = 0; i < RESOLUCION; ++i) {
        double theta     = theta_min + i * paso_theta;
        double cos2      = std::cos(theta) * std::cos(theta);
        double tan_theta = std::tan(theta);
        
        // El Z0 de despegue depende de la inclinación del robot con la pata extendida
        double z0_takeoff = LONGITUD_PATA_SALTO * std::sin(theta);
        double denom      = z0_takeoff + DIST_SALTO * tan_theta - h_objetivo;

        if (denom <= 0.0) continue;  // La trayectoria no alcanza la altura

        double v0_sq = (DIST_SALTO * DIST_SALTO * G) / (2.0 * cos2 * denom);
        if (v0_sq < v0_sq_min) {
            v0_sq_min = v0_sq;
            theta_opt = theta;
        }
    }

    if (std::isinf(v0_sq_min)) {
        RCLCPP_ERROR(this->get_logger(),
                     "Ninguna trayectoria alcanza h = %.2f m. Salto cancelado.", h_objetivo);
        return;
    }

    double v0 = std::sqrt(v0_sq_min);

    // Convertir a ángulo de inclinación del chasis (complementario al de lanzamiento)
    theta_opt_deg_ = 90.0 - theta_opt * (180.0 / M_PI);

    // Compresión necesaria del muelle
    double m_g_sin     = MASA_ROBOT * G * std::sin(theta_opt);
    double delta_x     = (m_g_sin + std::sqrt(m_g_sin*m_g_sin + 2*EFICIENCIA*(K_MUELLE_1 + K_MUELLE_2) * MASA_ROBOT * v0_sq_min)) / (2*EFICIENCIA*(K_MUELLE_1 + K_MUELLE_2));

    y_prep_salto_ = (LONGITUD_PATA_SALTO - delta_x) * std::sin(theta_opt);
    if (y_prep_salto_ < 0.02) y_prep_salto_ = 0.02;

    // --- Resultados de diagnóstico ---
    RCLCPP_INFO(this->get_logger(),
        "SALTO: v0=%.2f m/s | incl=%.1f° | dist=%.2f m | Δx_muelle=%.4f m | Y_prep=%.3f m",
        v0, theta_opt_deg_, DIST_SALTO, delta_x, y_prep_salto_);

    if ((delta_x*100) >= 2.4)
    {
        RCLCPP_WARN(this->get_logger(), "Compresión requerida (%.1f cm) excede el muelle. Salto NO viable.", delta_x * 100.0);
        movimiento_servo_  =0.0;
    } else {
        // Tiempo de activación del servo
        double t_servo_s = (Z2*Z4*Z_CARRETE*1023*delta_x) / (MG_0_1023 * Z1*Z3*Z5 * W_MAX_SERVO * R_CARRETE);
        movimiento_servo_ = t_servo_s*1000;
    }

    
}

// ============================================================
// MAIN
// ============================================================

int main(int argc, char **argv)
{
    rclcpp::init(argc, argv);
    rclcpp::spin(std::make_shared<Robot>());
    rclcpp::shutdown();
    return 0;
}

// ============================================================
// COMANDOS ÚTILES (referencia rápida)
// ============================================================
// ros2 run micro_ros_agent micro_ros_agent serial --dev /dev/ttyUSB0
// ros2 run tfg_salto tfg_robot
// ros2 topic pub -1 /cmd_salto std_msgs/msg/Float64 "{data: 0.04}"
// python3 teleop_teclado.py
//
// Servo gatillo (servo 9/10 en el array):
//   800  → gatillo cerrado (reposo / marcha)
//   920  → gatillo libre   (disparo)
//   1023 → muelle cargado  (armado)

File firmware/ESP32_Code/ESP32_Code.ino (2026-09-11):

#include <Arduino.h>
#include <micro_ros_arduino.h>
#include <stdio.h>
#include <rcl/rcl.h>
#include <rcl/error_handling.h>
#include <rclc/rclc.h>
#include <rclc/executor.h>
#include <std_msgs/msg/int32_multi_array.h>
#include <std_msgs/msg/int32.h>
#include <SCServo.h>

// --- CONFIGURACIÓN DE SERVOS ---
SCSCL sc; 
#define RX_PIN 16
#define TX_PIN 17

#define LED_PIN 2

const int n_servos = 10; 
u8 ids[n_servos] = {1, 8, 3, 2, 7, 6, 4, 5, 9, 10}; 

// --- OBJETOS DE MICRO-ROS ---
rcl_subscription_t subscriber;
rcl_subscription_t subscriber_salto;
rcl_publisher_t publisher_listo; 

std_msgs__msg__Int32MultiArray msg;
std_msgs__msg__Int32 msg_salto; 
std_msgs__msg__Int32 msg_listo; 

rclc_executor_t executor;
rclc_support_t support;
rcl_allocator_t allocator;
rcl_node_t node;

// --- VARIABLES DE TEMPORIZACIÓN PARA EL SERVO 9 ---
bool ejecutando_salto = false;
unsigned long tiempo_inicio_salto = 0;
unsigned long duracion_salto_ms = 0;

#define RCCHECK(fn) { rcl_ret_t temp_rc = fn; if((temp_rc != RCL_RET_OK)){error_loop();}}
#define RCSOFTCHECK(fn) { rcl_ret_t temp_rc = fn; if((temp_rc != RCL_RET_OK)){}}

void error_loop()
{
  while(1){
    digitalWrite(LED_PIN, !digitalRead(LED_PIN));
    delay(500); 
  }
}

// CALLBACK DE POSICIONES GENERALES
void subscription_callback(const void * msgin)
{
  digitalWrite(LED_PIN, !digitalRead(LED_PIN)); 

  const std_msgs__msg__Int32MultiArray * array_msg = (const std_msgs__msg__Int32MultiArray *)msgin;

  if (array_msg->data.size >= n_servos)
  {
    for(int i = 0; i < n_servos; i++)
    {
      int pos_objetivo = array_msg->data.data[i];

      if (ids[i] == 9)
      {
        // Ignorar órdenes del array general si estamos ejecutando el temporizador de salto
        if (!ejecutando_salto) {
          if (pos_objetivo < 0) pos_objetivo = 0;
          if (pos_objetivo > 2047) pos_objetivo = 2047;
          sc.WritePWM(9, pos_objetivo);
        }
      } 
      else 
      {
        // El servo 10 entrará automáticamente por aquí, en modo posición normal
        if (pos_objetivo < 0) pos_objetivo = 0;
        sc.WritePos(ids[i], (u16)pos_objetivo, 0, 0);
      }
    }
  }
}

// CALLBACK DE LA PETICION DE SALTO POR TIEMPO (ID 9)
void subscription_salto_callback(const void * msgin)
{
  const std_msgs__msg__Int32 * msg = (const std_msgs__msg__Int32 *)msgin;
  long tiempo_pedido = msg->data; // Milisegundos que debe estar girando
  
  // Solo aceptamos la orden si NO estamos ya haciendo un salto
  if (!ejecutando_salto && tiempo_pedido != 0) {
    
    ejecutando_salto = true;
    duracion_salto_ms = abs(tiempo_pedido);
    tiempo_inicio_salto = millis(); // Disparamos el cronómetro interno del ESP32
    
    if (tiempo_pedido > 0) {
      sc.WritePWM(9, 600);  // Hacia delante
    } else {
      sc.WritePWM(9, 2000); // Hacia atrás
    }
  }
}

void setup()
{
  pinMode(LED_PIN, OUTPUT);
  digitalWrite(LED_PIN, LOW);

  set_microros_transports();
  delay(100); 

  Serial2.begin(1000000, SERIAL_8N1, RX_PIN, TX_PIN); 
  sc.pSerial = &Serial2; 
  delay(500); 

  // Freno de emergencia en el arranque
  sc.WritePWM(9, 0);

  allocator = rcl_get_default_allocator();

  RCCHECK(rclc_support_init(&support, 0, NULL, &allocator));
  RCCHECK(rclc_node_init_default(&node, "nodo_esp32_esclavo", "", &support));

  RCCHECK(rclc_subscription_init_default(&subscriber, &node, ROSIDL_GET_MSG_TYPE_SUPPORT(std_msgs, msg, Int32MultiArray), "servo_poses"));
  RCCHECK(rclc_subscription_init_default(&subscriber_salto, &node, ROSIDL_GET_MSG_TYPE_SUPPORT(std_msgs, msg, Int32), "cmd_meta_salto"));
  RCCHECK(rclc_publisher_init_default(&publisher_listo, &node, ROSIDL_GET_MSG_TYPE_SUPPORT(std_msgs, msg, Int32), "estado_salto_listo"));

  // La capacidad ahora será automáticamente de 10
  msg.data.capacity = n_servos;
  msg.data.data = (int32_t*) malloc(msg.data.capacity * sizeof(int32_t));
  msg.data.size = 0;

  RCCHECK(rclc_executor_init(&executor, &support.context, 2, &allocator));
  RCCHECK(rclc_executor_add_subscription(&executor, &subscriber, &msg, &subscription_callback, ON_NEW_DATA));
  RCCHECK(rclc_executor_add_subscription(&executor, &subscriber_salto, &msg_salto, &subscription_salto_callback, ON_NEW_DATA));
}

void loop() {
  
  // --- MÁQUINA DE ESTADO DEL TEMPORIZADOR ---
  if (ejecutando_salto) {
    // Comprobamos si el cronómetro ya ha alcanzado el tiempo objetivo
    if (millis() - tiempo_inicio_salto >= duracion_salto_ms) {
      
      sc.WritePWM(9, 0); // FRENO DE EMERGENCI
      ejecutando_salto = false;

      // Avisamos a ROS 2 de que el tiempo se ha cumplido
      msg_listo.data = 1;
      RCSOFTCHECK(rcl_publish(&publisher_listo, &msg_listo, NULL));
    }
  }

  // --- PROCESAR MICRO-ROS ---
  RCSOFTCHECK(rclc_executor_spin_some(&executor, RCL_MS_TO_NS(10)));
}

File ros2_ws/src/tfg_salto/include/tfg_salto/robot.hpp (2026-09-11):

#ifndef ROBOT_HPP
#define ROBOT_HPP

#include "rclcpp/rclcpp.hpp"
#include "std_msgs/msg/int32_multi_array.hpp"
#include "std_msgs/msg/int32.hpp"
#include "std_msgs/msg/float64.hpp"
#include "geometry_msgs/msg/twist.hpp"
#include <cmath>
#include <limits>
#include <algorithm>
#include <chrono>

using namespace std::chrono_literals;

// ============================================================
// CONSTANTES CINEMÁTICAS DE LA PATA (metros)
// ============================================================
constexpr float D_PATA  = 0.022f;  // Separación entre los dos pivotes de la pata
constexpr float L1      = 0.020f;  // Longitud del eslabón superior izquierdo
constexpr float L2      = L1;      // Longitud del eslabón superior derecho (simétrico)
constexpr float L3      = 0.030f;  // Longitud del eslabón inferior izquierdo
constexpr float L4      = L3;      // Longitud del eslabón inferior derecho (simétrico)
constexpr double Z0     = 0.029;   // Altura de despegue del chasis (m)

// ============================================================
// CONSTANTES DE MARCHA
// ============================================================
constexpr float ALTURA_SUELO       = 0.040f;  // Altura nominal del chasis al suelo (m)
constexpr float ALTURA_LEVANT      = 0.015f;  // Altura que levanta la pata en el aire (m)
constexpr float Y_REPOSO           = 0.046f;  // Altura del chasis en posición de reposo (m)
constexpr int   CICLO_MS           = 3000;    // Duración de un ciclo de marcha completo (ms)
constexpr float FRACCION_AIRE      = 0.25f;   // Fracción del ciclo que la pata pasa en el aire

// ============================================================
// CONSTANTES DE MARCHA (servo de disparo)
// ============================================================
constexpr int SERVO_GATILLO_CERRADO = 800;    // PWM con el gatillo retenido
constexpr int SERVO_GATILLO_ABIERTO = 1023;   // PWM con el muelle cargado/gatillo armado
constexpr int SERVO_GATILLO_LIBRE   = 920;    // PWM al soltar (disparar) el muelle

// ============================================================
// CONSTANTES FÍSICAS DEL MECANISMO DE SALTO
// ============================================================
constexpr double MASA_ROBOT   = 0.370;   // Masa total del robot (kg)
constexpr double G            = 9.81;   // Gravedad (m/s²)
constexpr double K_MUELLE_1     = 170.0;  // Constante elástica del muelle (N/m)
constexpr double K_MUELLE_2     = 200.0;  // Constante elástica del muelle (N/m)
constexpr double EFICIENCIA   = 1.0;   // Eficiencia mecánica del muelle
constexpr double MU_FRICCION  = 0.90;   // Coeficiente de fricción estática
constexpr double DIST_SALTO   = 0.07;   // Distancia horizontal de despegue al obstáculo (m)
constexpr double ALT_OBSTAC_DEFAULT = 0.035; // Altura de obstáculo por defecto (m)
constexpr double LONGITUD_PATA_SALTO = 0.042;
constexpr int Z1 = 10;
constexpr int Z2 = 30;
constexpr int Z3 = 10;
constexpr int Z4 = 30;
constexpr int Z5 = 10;
constexpr int Z_CARRETE = 20;
constexpr int MG_0_1023 = 600;
constexpr double W_MAX_SERVO = 10.4719755;
constexpr double R_CARRETE = 0.004;


// Ciclos de pausa (a 50 Hz) al cambiar de estado
constexpr int CICLOS_PAUSA_ESTADO = 50; // 50 × 20 ms = 1 segundo

// ============================================================
// ESTRUCTURAS DE DATOS
// ============================================================

/// Parámetros hardware de calibración de una pata (canales y posiciones PWM)
struct ConfigHardware {
    int s1, s2;
    int pwm_horiz_s1, pwm_down_s1;
    int pwm_horiz_s2, pwm_down_s2;
};

/// Representa una pata con su configuración hardware y parámetros de marcha
struct Pata {
    ConfigHardware config;
    float desfase;    // Desfase de fase en el ciclo de marcha [0, 1)
    float inversor_x; // +1.0 o -1.0 según la orientación lateral de la pata
};

/// Estados de la máquina de estados del robot
enum Estado {
    ANDAR,
    AGACHADO,
    REPOSO,
    PREPARAR_SALTO,
    CARGAR_MUELLE,
    LIBERAR_MUELLE,
    RECUPERAR_REPOSO
};

// ============================================================
// CLASE ROBOT
// ============================================================
class Robot : public rclcpp::Node
{
public:
    Robot();
    ~Robot();

private:
    // --- Patas ---
    Pata misPatas_[4];

    // --- Máquina de estados ---
    Estado estado_actual_  = REPOSO;
    Estado estado_previo_  = REPOSO;
    bool   cambiado_       = false;  // true cuando se acaba de cambiar de estado
    int    ciclos_espera_  = 0;

    // --- Variables de locomoción ---
    float longitud_paso_     = 0.0f;
    float compensacion_giro_ = 0.0f;
    float altura_chasis_     = Y_REPOSO;
    rclcpp::Time tiempo_inicio_;   // Referencia temporal para la marcha

    // --- Variables de salto ---
    double h_objetivo_           = ALT_OBSTAC_DEFAULT; // Altura del obstáculo (m)
    double theta_opt_deg_        = 0.0;  // Ángulo óptimo de salto (grados)
    float  theta_actual_         = 0.0f; // Ángulo de inclinación actual del chasis (grados)
    int    movimiento_servo_     = 0;    // Duración de tensado del servo (ms)
    bool   orden_salto_enviada_  = false;
    double y_prep_salto_ = 0.0;

    // --- Fase interna del estado LIBERAR_MUELLE ---
    int             fase_liberacion_      = 0;
    bool            timer_liberacion_set_ = false;
    bool            timer_disparo_set_    = false;
    rclcpp::Time    tiempo_fase_;
    
    // --- Control de transiciones temporales (Interpolación) ---
    bool   transicion_activa_ = false;
    double duracion_transicion_ = 0.0;
    rclcpp::Time tiempo_inicio_transicion_;
    float  y_inicial_ = 0.0f, y_final_ = 0.0f;
    float  theta_inicial_ = 0.0f, theta_final_ = 0.0f;

    // Métodos para gestionar las transiciones de tiempo
    void iniciarTransicion(float y_fin, float theta_fin, double duracion_segundos);
    bool actualizarTransicion(float &out_y, float &out_theta);
    
    // Nuevo estado
    void estado_recuperar_reposo();

    // --- ROS: Publishers ---
    rclcpp::Publisher<std_msgs::msg::Int32MultiArray>::SharedPtr pub_poses_;
    rclcpp::Publisher<std_msgs::msg::Int32>::SharedPtr           pub_meta_salto_;

    // --- ROS: Subscriptores ---
    rclcpp::Subscription<geometry_msgs::msg::Twist>::SharedPtr  sub_vel_;
    rclcpp::Subscription<std_msgs::msg::Int32>::SharedPtr       sub_estado_;
    rclcpp::Subscription<std_msgs::msg::Float64>::SharedPtr     sub_salto_;
    rclcpp::Subscription<std_msgs::msg::Int32>::SharedPtr       sub_salto_listo_;

    // --- ROS: Timer principal ---
    rclcpp::TimerBase::SharedPtr timer_control_;
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

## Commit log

2026-09-11 All Uploaded
    [Ensamblaje Pata.SLDASM, Ensamblaje Vahículo Saltador 2_2024.SLDASM, Ensamblaje chasis superiopr.SLDASM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]
2026-09-11 Remove placeholder for prototype images in README
    Removed placeholder for SolidWorks renders and prototype photos.

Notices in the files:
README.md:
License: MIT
